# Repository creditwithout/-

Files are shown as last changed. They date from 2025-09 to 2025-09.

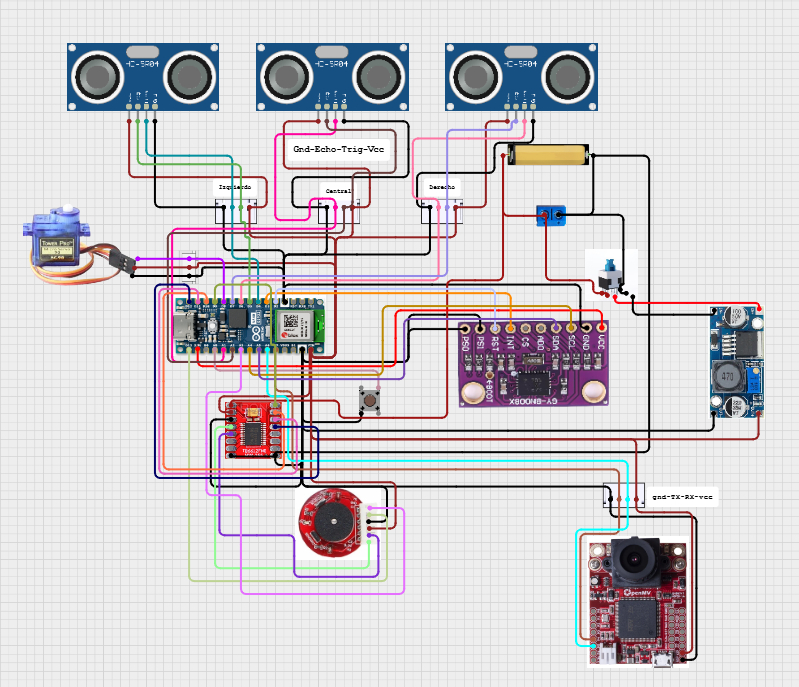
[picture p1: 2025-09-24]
SCHEMES/Cirkit Designer/Captura de pantalla 2025-09-23 232917.png

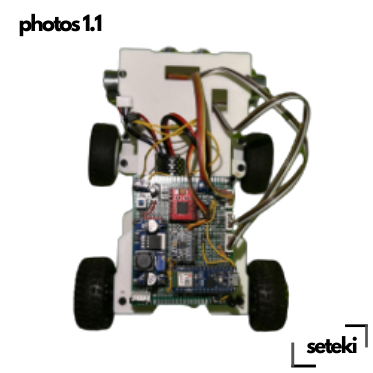
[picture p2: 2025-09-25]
robot photos/1.1/top 1.1.png

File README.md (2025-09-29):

> [!WARNING]
> This repository isn't finished yet, wait until saturday. Any question contact us at setekiteam@gmail.com.
<br>

> [!CAUTION]
> Due to GitHub problems some charts and GIFs can load a little bit slow, so we beg you to be patient while reading to not miss anything, THANKS!

# Seteki® Team🤖
Add a subheading (16 x 5 cm) (4096 x 2160 px)
## Beyond the future! 😎
Animated header







This is the official repository of the Seteki® team that will represent Instituto Episcopal San José in the WRO category: Future Engineers 2025, Panama.
<br><br>

## Overview of our repository folders 📜

```
📦 WRO2025 Seteki
├── 📁 3D-models             # Contains 3D design files for the robot's components
│   ├── 📁 1.1               # 1.1 Models
│   ├── 📁 2.14              # 2.14 Models
│   ├── 📁 3.1 (National)    # 3.1 Models
│   ├── 📁 3D Printer and    # filaments
│   └── 📄 README.md         # 3D models explained
├── 📁 Ara Versions          # Contains an explanation of every ARA Robot
│   ├── 📁 1.1               # ara 1.1
│   ├── 📁 2.14              # 2.14
│   ├── 📁 3.1(National)     # 3.1
│   ├── 📄 ara.md            # A tiny graph of the models
│   └── 📄 README.md         # Explanation of every model
├── 📁 Components            # Every Robot component with and extended information
│   ├── 📁 Arduino Nano ESP32# microcontroller
│   ├── 📁 BNO086            # IMU
│   ├── 📁 HC-SR04           # ultrasonics
│   ├── 📁 INJORA SERVO      # Servomotor
│   ├── 📁 LM2596            # Regulator
│   ├── 📁 MOTOR             # POLOLU
│   ├── 📁 OPEN MV H7 PLUS   # Camera
│   ├── 📁 TB6612FNG         # Motor Driver
│   └── 📄 README.md         # Explanation
├── 📁 SCHEMES               # All of the circuit
│   ├── 📁 Cirkit designer   # Interactive circuit
│   ├── 📁 Fritzing          # Our Circuit in Fritzing
│   ├── 📁 PCB               # Every Of the realization of our PCB
│   └── 📄 README.md         # Explanation
├── 📁 GitHub Printables     # All PDF Githubs ready to print
│   ├── 📁 1.1               # 1.1 pdf
│   ├── 📁 2.14              # 2.14 pdf
│   ├── 📁 3.1(national)     # 3.1 pdf
│   └──📄 README.md          # Explanation
├── 📁 media                 # All our social media
│   └──📄 README.md          # Explanation
├── 📁 Robotlogic & analysis # How our robot is working
│   ├── 📁 Flowcharts        # Flowcharts with explanation
│   ├── 📁 Graphics          # Seteki random photo xd
│   └──📄 README.md          # Explanation
├── 📁 Robot Photos          # Robot videos
│   ├── 📁 1.1               # 1.1 Photos and explanation
│   ├── 📁 2.14              # 2.14 Photos and exlplanation
│   ├── 📁 3.1 (National)    # 3.1 Photos and explanation
│   └──📄 README.md          # 3.1 Photos
├── 📁 src                   # Robot videos
│   ├── 📁 First Challenge   # Codes of the first round
│   ├── 📁 Second Challenge  # Codes of the second round
│   └──📄 README.md          # Explanation
├── 📁 Team Analysis         # Other project studies
│   ├── 📁 Work Schedule     # work time
│   ├── 📁 project cost analy# cost history 3.1
│   ├── 📁 workflow          # a diagram of how we work
│   └──📄 README.md          # Explanation
├── 📁 team photos           # Our photos as participant
│   ├── 📁 Funny photos      # All the funny photos
│   ├── 📁 Photos with tutor # Our photos with our tutor
│   ├── 📁 formal with tutor # Our photos with our tutor
│   ├── 📁 members           # There´s a lot of individual photos
│   └──📄 README.md          # Explanation
├── 📁 video                 # All the robot videos
│   ├── 📁 First Challenge   # All videos of first round
│   ├── 📁 Other videos      # Other explicative videos
│   ├── 📁 Second Challenge  # All videos of the second round
│   └──📄 README.md          # Explanation
└── 📄 README.md             # Main documentation for the project
```

> [!CAUTION]
> Due to GitHub problems some charts and GIFs can load a little bit slow, so we beg you to be patient while reading to not miss anything, THANKS!

## About Us🗣️

<div align="center">
  Trabajo grupal de Los Sentidos Ilustativo Colorido (40 x 25 cm)
</div>

We are Team Seteki, proudly representing Instituto Episcopal San José in Panama’s World Robot Olympiad (WRO) Future Engineers 2025 category. Our mission is to blend technology and innovation, knowing that innovation can go hand-in-hand with responsability.

### Our Philosophy 😎
We are a team in which there are no hierarchies in the team, we each develop our parts and we are all involved and we `KNOW` every part of the realization of this whole project that would be our robor [ARA](https://github.com/creditwithout/-/tree/main/ARA%20Versions), we have values of humility and perseverance as a team, both when we work as a team as well as when we go to compete, we are a team in which two already have experience in what is robotics and specifically the WRO competition and we have a rookie in this world of what robotics is.

With our project we want to innovate and bring something that is well worked to this competition, we want the effort put into this robot to be noticed.

The truth is that our team is in a balance that we feel comfortable and perfect, each one develops a part that is essential for the other part, so we need each other and are values that apart from robotics and technological competition, are values that the WRO is also seeking to establish in all its competitors.

Without further ado, let's continue btw :) 

## Team Name Explication 🥸

The name of our Team ( [Seteki](https://es.wikipedia.org/wiki/Atelopus_zeteki) ), comes from an animal called ‘'[ ***Atelopus zeteki*** ](https://static.inaturalist.org/photos/56362/medium.jpg)’'. 
It is a small species of anuran amphibian of the Bufonidae family.

<div align="center">
  Texto descriptivo
</div>

When we chose this name, it was because we are people who are using the possible resources to develop these robots and technology, but sometimes we forget that all this comes from natural resources and we are taking advantage of all this and we do not take care of it, and as a small annex we wanted to give this message that we also have a responsibility to the world and in addition to this we also want to have our country represented in our team.

> [!WARNING]
> This species is in danger of extinction, more information [here](https://es.wikipedia.org/wiki/Especie_en_peligro_cr%C3%ADtico_de_extinci%C3%B3n).
<br>

## Team presentation 😒

### Jean Sosa
| Name | Description & Rol | GIF | Age | IG | More |
|:---|:---|:---|:---|:---|:---|
| Jean Paul Sosa Cruz  | Robot logic developer, 3D designer and 3D printing, Robot documentation as well as team workflow. for him all is music, and playing instruments, and has a good trayectory in robotics. | Texto descriptivo | 18 |  | [More about him](https://github.com/creditwithout/-/tree/main/team%20photos/members/Jean%20Paul)

### Jonathan Sosa
| Name | Description & Rol | GIF | Age | IG | More |
|:---|:---|:---|:---|:---|:---|
| Jonathan Michael Sosa Cruz  | He is the mechanical genius of the team, he repairs and builds anything and he is in charge of all the robot's circuitry, he only thinks about soccer and getting home to play the bass guitar. | Texto descriptivo | 15 |  | [More about him](https://github.com/creditwithout/-/tree/main/team%20photos/members/Jonathan%20Michael)

### Anthony Gomez
| Name | Description & Rol | GIF | Age | IG | More |
|:---|:---|:---|:---|:---|:---|
| Anthony Bruce Gomez Arjona  | He is the nerdiest of the three, he is the scientist and physicist of the team, he is the developer of the logic and he is in charge of the programming, talk to him about jurasic park and you will have all his attention. | Texto descriptivo | 17 |  | [More about him](https://github.com/creditwithout/-/tree/main/team%20photos/members/Anthony%20Bruce)

### Edgar Ruiz
| Name | Description & Rol | GIF | Age | IG | More |
|:---|:---|:---|:---|:---|:---|
| Edgar Antonio Ruiz Caballero  | Active participant in robotics competitions such as RoboCup Jr , WRO, and others since 2015. - National Winner of RoboCup Jr 2017 and team coachrepresenting Panama in Nagoya, Japan. - Third Place National Winner in WRO 2018 as team coach for The Oxford School. - National Winner of RoboCup Jr 2018 and team coach representing Panama in Sydney, Australia in 2019. - Participant in 2021 STEAM training hosted by Grupo Editorial EDELVIVES in Madrid, Spain. - National Winner of WRO 2022 and team coach representing Panama in Dortmund, Germany. - National Winner of WRO 2024 (World Robot Olympiad) and team coach representing Panama in Izmir, Turkey. | Texto descriptivo | 26 |  | [More about him](https://github.com/creditwithout/-/tree/main/team%20photos/Photos%20with%20tutor)

> [!IMPORTANT]
> You can fin more information of every member by clicking [here](https://github.com/creditwithout/-/tree/main/team%20photos/members).
<br>

## Team Photos😁
- ### [Formal Photo](https://github.com/creditwithout/-/tree/main/team%20photos/formal%20photos)
- ### [Funny Photos](https://github.com/creditwithout/-/tree/main/team%20photos/Funny%20photos)
- ### [Photos with tutor](https://github.com/creditwithout/-/tree/main/team%20photos/Photos%20with%20tutor)

## Robot Name Explication😶‍🌫️

Add a subheading (16 x 5 cm) (4096 x 2160 px) (18)

The name of all versions of our robot (ARA) comes from  [***Ara macao***](https://es.wikipedia.org/wiki/Ara_(animal)#:~:text=Ara%20macao%20(Linnaeus%2C%201758),cyanopterus%20Wiedenfeld%2C%201995%E2%80%93), practically the name of the macaw family. Macaws are large parrots measuring 46 to 51 cm in length and weighing 285 to 287 g in the case of the great macaw, and 90 to 95 cm and 1,708 g in the case of the green-winged macaw.

<div align="center">
  Texto descriptivo
</div>

> [!NOTE]
> More information [here](https://ebird.org/species/scamac1?siteLanguage=es_PA).
<br>

### Robot Versions🚘

| 1.1 | 2.14 | 3.1 (National) |
|:---|:---|:---|
| It's the same configuration than 1.0 version, but de 3D designs had a big improvement.  [more information](https://github.com/creditwithout/-/tree/main/ARA%20Versions/1.1) | this one has 3 ultrasonics and a great improvement in 3D designs. [more information](https://github.com/creditwithout/-/tree/main/ARA%20Versions/2.14) | Has a differential included and more angle for steering [more about](https://github.com/creditwithout/-/tree/main/ARA%20Versions/3.1%20(National)) |

## Mobility Management 

### `3D Models`
- In the [3D Model](https://github.com/creditwithout/-/tree/main/3D%20Models) Folder you will find and extended information about everything relationated with 3D pieces in the robot, an also explaining how we build our differential traction, all about the steering, and also the printer and the filaments we use for the project, anyway here we'll explain all about the differential.

You can also visualize all our 3D Model for the 1.1, 2.14 and the National version By going here

> [!NOTE]
>You can also visualize all our 3D Model for the 1.1, 2.14 and the National version By going [here](https://github.com/creditwithout/-/tree/main/3D%20Models) .
<br>

### ` Differential `

7d3144b8-8908-438d-ba55-42e69fd148e3

`Why we use this mechanism?`
- Because using this mechanism mainly helps us when leaving and parking in the parking lot, since when the robot without differential makes a turn, the wheels will be turning at the same speed, which does not help us since obviously in a turn one wheel will have to travel further than the other, so when the robot has to turn with the differential, it will avoid this skidding that can cause our  old pinion and axle system.

- Some disadvantages are that with the 2.14 robot after the second regional, that well-optimized robot with an 800 RPM motor was doing it in `25 seconds`, but the transmission of speed when there are more gears will cause our robot to go slower, so now we are doing the first round in `42 seconds`.

> [!NOTE]
> [in this folder here](https://github.com/creditwithout/-/tree/main/3D%20Models/3.1%20(National)) You can watch assembly animations of our car.
<br>

<div align="center">
  Texto descriptivo
</div>

## Power Management
Usamos una bateria de [litio 12v](https://github.com/creditwithout/-/tree/main/Components) Con la que la alimentamos al cicuito y al [driver de motor](https://github.com/creditwithout/-/tree/main/Components/TB6612FNG) with which we power our motor. You can find a more detailed explanation of this in the circuits folder, where we explain everything about voltage management and how the voltage components are connected in the robot.

- ### [More information](https://github.com/creditwithout/-/tree/main/SCHEMES/Fritzing/circuit)

## Robot Components
> [!NOTE]
> [in this folder here](https://github.com/creditwithout/-/tree/main/Components) you can find an extended datasheet redacted by the team about every component in the robor.
<br>

 Every robot electrical component
- `Ultrasonic Sensors` [3] [HC-SR04](https://naylampmechatronics.com/blog/10_tutorial-de-arduino-y-sensor-ultrasonico-hc-sr04.html)
  - [Buy Here](https://www.amazon.es/DIGISHUO-ultras%C3%B3nico-medici%C3%B3n-distancia-bricolaje/dp/B0DPZTNKHD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)
  - [More information here](https://github.com/creditwithout/-/tree/main/Components/HC-SRO4)  
- `Motor Driver` [1] [Puente H TB6612FNG 1.2A](https://naylampmechatronics.com/drivers/200-driver-puente-h-tb6612fng.html)  
  - [Buy Here](https://www.amazon.es/CCCAZ1-Controlador-Motor-Microcontrolador-TB6612FNG/dp/B0DM5ZBBH5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)
  - [More information here](https://github.com/creditwithout/-/tree/main/Components/TB6612FNG)
- `Servo motor` [1] [INJORA 11KG](https://www.injora.com/products/injora-injs2065-7kg-high-voltage-waterproof-2065-digital-servo-with-mount-for-1-18-trx4m)
  - [Buy Here](https://www.amazon.com/-/es/digital-impermeable-voltaje-Sub-Micro-Crawler/dp/B0BLBMVYCW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)
  - [More informmation here](https://github.com/creditwithout/-/tree/main/Components/INJORA%20SERVO%2011KG)
- `Motor` [1] [Metal Gearmotor 25Dx65L mm HP 12V with 800 rpm Encoder](https://www.pololu.com/product/4843)
  - [Buy Here](https://www.pololu.com/product/4843)
  - [More information here](https://github.com/creditwithout/-/tree/main/Components/MOTOR)
- `Voltage Regulator` [1] [LM2596](https://naylampmechatronics.com/conversores-dc-dc/196-convertidor-voltaje-dc-dc-step-down-3a-lm2596.html)
  - [Buy Here](https://www.amazon.com/LM2596-Convertidor-alimentaci%C3%B3n-Estabilizador-electr%C3%B3nico/dp/B08RS9BSGB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)
  - [More information here](https://github.com/creditwithout/-/tree/main/Components/LM2596)
- `Interruptor Latching` [1] [Tact Switch](https://es.aliexpress.com/item/32946132279.html?gatewayAdapt=glo2esp)
  - [Buy Here](https://www.amazon.com/-/es/TWTADE-surtido-interruptores-moment%C3%A1neo-valores/dp/B0858XRGYW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)
- `Capacitors` [2] [capacitors](https://quartux.com/blog/que-es-un-capacitor-o-condensador-electrico/)
  - [Buy Here](https://www.amazon.com/ALLECIN-surtido-condensadores-electrol%C3%ADticos-aluminio/dp/B0C1VBXCQM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)
- `Male female conectors` [12] [XH-4Y](https://www.walmart.com/ip/2-54mm-Pitch-Connector-Kits-4-Pin-Male-Female-Header-Socket-4Pin-Housing-Cable-Adapter-and-Crimp-DIP-Kit-600pcs/1723812568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)
  - [Buy Here](https://www.amazon.com/-/es/JST-conectores-terminales-compatible-XH2-2-126/dp/B0DN6LGG94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)
- `Gyroscope BNO086` [1] [BNO086 (IMU Sensor)](https://naylampmechatronics.com/blog/45_tutorial-mpu6050-acelerometro-y-giroscopio.html)
  - [Buy Here](https://www.amazon.com/-/es/unidades-GY-521-aceler%C3%B3metro-giroscopio-convertidor/dp/B07RXQGGJX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)
  - [More information](https://github.com/creditwithout/-/tree/main/Components/BNO086)
- `Micro-controller` [1] [Arduino NANO ESP32](https://store.arduino.cc/products/nano-esp32?srsltid=AfmBOor1ZPTTOx_mqwjYCxh9cpnrrSOmZiry-TUbDsQwkmkYgxsAu0NA)
  - [Buy Here](https://www.amazon.com/-/es/Arduino-Nano-ESP32-encabezados-ABX00083/dp/B0C947BHK5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)
  - [More information](https://github.com/creditwithout/-/tree/main/Components/Arduino%20Nano%20ESP32)
- `Terminal` [1] [PCB Terminal](https://www.ebay.com/itm/176852835599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)
  - [Buy Here](https://www.amazon.com/Conector-terminales-proyectos-electr%C3%B3nica-dom%C3%A9stica/dp/B09ZXK9WHW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)
- `Prototype wires` [32] [Prototype wires](https://shop.complubot.com/10-cables-prototipado-m--m-100-mm-p-1-50-142/)
  - [Buy Here](https://www.amazon.com/b%C3%B3vedas-0-079-4-921-Flexible-Breadboard-Connecting/dp/B08YRGVYPV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)
- `Normal Wires` [11] [Normal Wires](https://electric-house.com/en/new-cables-wires-accessories/british-standard-wires-nya/normal-nya-wires.html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)
  - [Buy Here](https://www.amazon.com/Aypzuke-compatible-proyectos-Arduino-Raspberry/dp/B0BTT31CBC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)
- `Camera` [1] [Open MV H7 Plus](https://openmv.io/products/openmv-cam-h7-plus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)
  - [Buy Here](https://www.amazon.com/-/es/OpenMV-Cam-Plus-Procesamiento-Aprendizaje/dp/B09WYQMDX2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)
  - [More information](https://github.com/creditwithout/-/tree/main/Components/Open%20MV%20H7%20Plus)
- `Lipo Battery` [1] [Airsoft LIPPO Battery 11.1V](https://ampedairsoft.com/high-power-airsoft-hpa-lipo-battery-deans/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)
  - [Buy Here](https://ampedairsoft.com/high-power-airsoft-hpa-lipo-battery-tamiya/)
- `Ceramic Capacitors` [2] [Ceramic Capacitors](https://ampedairsoft.com/high-power-airsoft-hpa-lipo-battery-deans/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)
  - [Buy Here](https://ampedairsoft.com/high-power-airsoft-hpa-lipo-battery-tamiya/)

> [!WARNING]
> You can see a more extenden explanation of every component in the folders, anyway in the component list you can find the link to go to a extended explanation of every component, thanks
<br>

## Schemes

For the national we aim to improve all of our circuit, we decide to give to the judges more interactive circuit an better explanation un the folders just to have a better understanding on everything around the project.

- ### [Cirkit designer](https://github.com/creditwithout/-/tree/main/SCHEMES/Cirkit%20Designer)
- ### [Cirkit designer cirkit public viewer](https://app.cirkitdesigner.com/project/14ea10bb-b8b8-4b1f-92cd-de119d128b88)
- ### [Fritzing](https://github.com/creditwithout/-/tree/main/SCHEMES/Fritzing)
- ### [PCB](https://github.com/creditwithout/-/tree/main/SCHEMES/PCB)

### `PCB 3D VIEWER`

Trabajo grupal de Los Sentidos Ilustativo Colorido (Mobile Video) (6)

## Robot logic and analysis

For us, it is very important that when explaining our robot, we can use diagrams and graphs that show the actual flow of logic, programming, and all the decisions that enable our ARA Robot to execute its respective rounds. We have flowcharts that show the decisions to be followed for each round, as well as specialized diagrams of the internal decisions made by some components within the code. We also have graphs that explain the actual operation mathematically and physically, with very short standard deviations in the execution of everything.

- ### [Flowcharts](https://github.com/creditwithout/-/tree/main/robot%20logic%20and%20analysis/flowcharts)
   - #### [First Challenge](https://github.com/creditwithout/-/tree/main/robot%20logic%20and%20analysis/flowcharts/First%20challenge)
   - #### [Second Challenge](https://github.com/creditwithout/-/tree/main/robot%20logic%20and%20analysis/flowcharts/Second%20Challenge)
     
- ### [Graphics](https://github.com/creditwithout/-/tree/main/robot%20logic%20and%20analysis/graphics)

## SRC
Here you will find the two complete source codes for each round, in order to remain faithful to the engineering process, as well as detailed explanations of the most interesting and complex parts of our codes.

- ### [First Challenge](https://github.com/creditwithout/-/tree/main/src/First%20Challenge)

- ### [Second Challenge](https://github.com/creditwithout/-/tree/main/src/Second%20Challenge)
    - ### [Camera](https://github.com/creditwithout/-/tree/main/src/Second%20Challenge/camera)

## [Team Analysis](https://github.com/creditwithout/-/tree/main/team%20analysis)

- ### [Work team Schedule](https://github.com/creditwithout/-/tree/main/team%20analysis/Work%20Schedule)
- ### [Project cost Schedule](https://github.com/creditwithout/-/tree/main/team%20analysis/project%20cost%20analysis)
- ### [WorkFlow](https://github.com/creditwithout/-/tree/main/team%20analysis/workflow)

## Performative Videos

### `You'll find every video in` [here](https://github.com/creditwithout/-/tree/main/video)

## Media

### 'And all our social media, clash royal clan and web page in' [here](https://github.com/creditwithout/-/tree/main/media%20)

---

## References
https://fritzing.org/download/
https://openmv.io/pages/download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
https://www.ni.com/es/shop/labview/pid-theory-explained.html#:~:text=Un%20controlador%20PID%20es%20un,%2C%20velocidad%2C%20presi%C3%B3n%20y%20voltaje.
https://www.arduino.cc/
https://es.wikipedia.org/wiki/Arduino
https://wro-association.org/
https://es.wikipedia.org/wiki/Microcontrolador#:~:text=Un%20microcontrolador%20(abreviado%20%C2%B5C%2C%20UC,que%20cumplen%20una%20tarea%20espec%C3%ADfica.
https://es.wikipedia.org/wiki/Impresi%C3%B3n_3D
https://scoring.wro-association.org/es/
https://docs.github.com/es/get-started/writing-on-github/getting-started-with-writing-and-formatting-on-github/basic-writing-and-formatting-syntax
https://es.wikipedia.org/wiki/Sensor_ultras%C3%B3nico
https://naylampmechatronics.com/

> [!CAUTION]
> Due to GitHub problems some charts and GIFs can load a little bit slow, so we beg you to be patient while reading to not miss anything, THANKS!

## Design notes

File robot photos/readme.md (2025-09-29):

# Robot Photos
Add a subheading (16 x 5 cm) (4096 x 2160 px) (2)
Here you will find not only photos of the ARA 3.1 national version, but also photos of the robot that competed in the two previous regional competitions, thus maintaining the competition's philosophy of creating an engineering process and documenting everything along the way.

# End Page 
Seteki 2025 - Robot photos

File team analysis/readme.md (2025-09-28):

# Team Analysis
Add a subheading (16 x 5 cm) (4096 x 2160 px) (17)

Here you'll find the work schedule and the workflow of the journey in this project and also a cost analysis just for the ARA ROBOT 3.1

# End Page
Seteki 2025 - Team analysis

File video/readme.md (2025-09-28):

# ARA 3.1 Challenges videos

Add a subheading (16 x 5 cm) (4096 x 2160 px) (16)

## [Here](https://www.youtube.com/@setekiteam) you can visit our youtube video, and every folder will have the link to the exact video, and briefly mp4 short.

# End Page
Seteki 2025 - Videos

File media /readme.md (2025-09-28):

# All Our Social Media

Copy of Add a subheading (16 x 5 cm) (4096 x 2160 px) (12)

We count with several ways to share our project with the world!

 - [Youtube](https://www.youtube.com/@setekiteam)

Here you'll find not just the videos of the robot making the rounds, you'll also find other type of videos where we are explaining the project.

 - [Instagram](https://www.instagram.com/setekiteam/)

Here you'll find our day to day, because this is a engineering process.

 - [Clash royal seteki clan](https://link.clashroyale.com/invite/clan/es?tag=G8YULLJP&token=3jhdxkac&platform=iOS)

Being in robotics is also a lot of getting mentally tire, so sometimes is okey to distract your mind with hobbies like music, sports, games and then get fresh to get back to work, that's why we have a seteki clash royal CLAN. jijijija!

 - [Seteki web page](https://seteki.vercel.app/)

Copy of Add a subheading (16 x 5 cm) (4096 x 2160 px) (14)

# End Page
Seteki 2025 - MEDIA

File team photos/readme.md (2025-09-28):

# Team Photos🦾
Add a subheading (16 x 5 cm) (4096 x 2160 px) (3)

# End Page
Seteki 2025

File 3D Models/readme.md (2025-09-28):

# Every 3D models
Copy of Add a subheading (16 x 5 cm) (4096 x 2160 px)

In this set of folders, you will find all the models that can be viewed and downloaded in ``` (.stl) ``` files for all the models of our ARA robot. Each folder will also have an explanation of all the 3D models corresponding to each version. To review the current version of the national competition in Panama 2025, check folder ```3.1```, where you will find everything related to the robot that will compete in the national competition.



--------------------------
### Seteki -- 3D Models

# End Page 
Seteki 2025 - 3D models

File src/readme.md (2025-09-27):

# SRC Folder

Add a subheading (16 x 5 cm) (4096 x 2160 px) (8)

In this folder, you will find all the codes and most important parts explained and documented in English. The readme file explains the fundamental parts, and the complete code will be uploaded to the same folder in its respective native file format, with each code commented on in English and accompanied by a detailed explanation.

## Here you'll find:

- ### [First Challenge](https://github.com/creditwithout/-/tree/main/src/First%20Challenge) 
- ### [Second Challenge](https://github.com/creditwithout/-/tree/main/src/Second%20Challenge)
   - [Camera Code](https://github.com/creditwithout/-/tree/main/src/Second%20Challenge/camera)

# End Page
Seteki 2025 - SRC

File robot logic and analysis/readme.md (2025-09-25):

# Robot logic and analysis.
Add a subheading (16 x 5 cm) (4096 x 2160 px) (1)

Here we can find physical and mathematical explanations of everything that happens in the robot's programming and logic. We will also find flowcharts of the autonomous decisions made by each component, and graphs that show specific problems graphically so that they can be better understood.

# End Page
Seteki 2025 - Robot logic and analysis

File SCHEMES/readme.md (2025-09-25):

# Schemes

Copy of Add a subheading (16 x 5 cm) (4096 x 2160 px) (6)

This folder contains in-depth information about our robot's circuit, including our PCB, explanations, and various diagrams, especially about the circuit. Everything is covered in depth here, because the main readme file is much more summarized than the folders.

Trabajo grupal de Los Sentidos Ilustativo Colorido (Mobile Video) (6)

# End page
Seteki 2025 - Schemes

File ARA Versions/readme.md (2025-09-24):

# Every ARA Robot that has faced a competition 😁

Copy of Add a subheading (16 x 5 cm) (4096 x 2160 px) (1)

### Robot Versions🚘

| 1.0 | 1.1 | 2.12 | 2.13 | 2.14 | 3.1
|:---|:---|:---|:---|:---|:---|
| It has 3 ultrasonics, No differential | It's the same configuration than 1.1 version, but de 3D designs had a big improvement. | Has only camera, no ultrasonics, has a differential integrated. | This one has 2 ultrasonics and the camera, we quit differential to keed developing it | this one has 3 ultrasonics and a great improvement in 3D designs. | THIS ONE INTEGRATE A DIFFERENTIAL IN THE TRACTION AND HAS 3 ULTRASONICS, AND NOW COUNTS WITH A DESIGNED PCB AND MANUFACTERED IN HONG KONG, FOR MAKE OUR CIRCUIT A LOT BETTER. |

## NATIONAL

For the national our robot is the ARA 3.0

Trabajo grupal de Los Sentidos Ilustativo Colorido (7)

# end page - seteki
Seteki 2025 - GitHub 3.1 - creditwhitout [Home main page](https://github.com/creditwithout/-/blob/main/README.md)

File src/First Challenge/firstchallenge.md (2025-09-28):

```ino
#include "SparkFun_BNO080_Arduino_Library.h"
#include <Wire.h>
#include <ESP32Servo.h>
#include <stdlib.h>
#include <math.h>
#include <string.h>

#if __has_include(<NewPing.h>)
#include <NewPing.h>
#define USE_NEWPING 1
#else
#define USE_NEWPING 0
#endif

// ==================== CONFIGURABLE PARAMETERS ====================
// IMU and I2C bus configuration
const uint8_t I2C_SDA_PIN = A4;  // Current user wiring configuration
const uint8_t I2C_SCL_PIN = A5;    // I2C clock line pin
const uint8_t BNO08X_INT_PIN = 2;  // BNO080 interrupt pin for data ready signal
const uint8_t BNO08X_RST_PIN = 3;  // BNO080 reset pin for hardware reset capability
const uint8_t BNO08X_ADDR = 0x4B;  // I2C address of BNO080 sensor

// Motor driver and auxiliary hardware pins
const int pwma = 9;           // PWM control pin for motor speed
const int ain2 = 10;          // Motor direction control pin (L298N)
const int ain1 = 11;          // Motor direction control pin (L298N)
const int stby = 12;          // Standby pin to enable/disable motor driver
const int startButtonPin = A0; // Start button input pin

// Servo motor configuration
const int servoPin = 8;        // Servo control pin
const int servoNeutral = 90;    // Neutral position (straight ahead)
const int servoMinAngle = 10;   // Minimum servo angle limit
const int servoMaxAngle = 170;  // Maximum servo angle limit

// Ultrasonic sensor configuration
#define TRIG_IZQUIERDO 5    // Left ultrasonic trigger pin
#define ECHO_IZQUIERDO 4     // Left ultrasonic echo pin
#define TRIG_CENTRO A2       // Center ultrasonic trigger pin
#define ECHO_CENTRO A1       // Center ultrasonic echo pin
#define TRIG_DERECHA 6       // Right ultrasonic trigger pin
#define ECHO_DERECHA 7       // Right ultrasonic echo pin
const unsigned int MAX_US_DISTANCE_CM = 200;     // Maximum measurable distance
const long TIMEOUT_ULTRASONICO = 20000;          // Timeout for ultrasonic readings
const float DISTANCIA_MAX_VALIDA = 500.0;        // Maximum valid distance reading
const float DISTANCIA_MIN_VALIDA = 1.0;          // Minimum valid distance reading
const float umbralRatioLateral = 0.6;            // Lateral threshold ratio for opening detection
const float umbralRatioCentral = 1.3;            // Central threshold ratio for wall detection
const unsigned long MIN_INTERVALO_PING_MS = 15; // Minimum interval between ultrasonic pings

// PID controller parameters for yaw control
float Kp = 1.5, Ki = 0.01, Kd = 0.2;        // Normal navigation PID gains
float Kp_turn = 0.5, Ki_turn = 0.25, Kd_turn = 1.00;  // Turning maneuver PID gains
float Kp_stab = 1.02, Ki_stab = 0.03, Kd_stab = 1.00; // Stabilization PID gains
const unsigned long sampleInterval = 20;       // PID sample time in microseconds
const float integralLimit = 40.0;              // Integral windup protection limit
const float deadband = 0.5;                    // Deadband for yaw error to prevent oscillation

// Maneuver timing and control parameters
const unsigned long TIMEOUT_MANIOBRA = 4000;           // Maximum time for turn maneuver
const float TURN_ANGLE_TOLERANCE = 2;                   // Angle tolerance for turn completion
const unsigned long tiempoEstabilizacion = 300;        // Stabilization phase duration
const unsigned long tiempoCorreccion = 400;            // Correction phase duration
const unsigned long TIMEOUT_CORRECCION = 800;          // Maximum correction phase timeout
const float CORRECTION_ANGLE_TOLERANCE = 5;             // Yaw stability tolerance for correction
const int NUM_CURVAS_ANTES_DE_PARAR = 12;              // Number of turns before parking sequence

// Motor speed settings for different phases
const int velocidadNormal = 255;        // Normal navigation speed
const int velocidadGiro = 255;          // Turning maneuver speed
const int velocidadEstabilizacion = 255; // Stabilization phase speed
const int velocidadCorreccion = 255;     // Correction phase speed
const int velocidadCorreccionMin = 180;  // Minimum correction speed for ramping
const int velocidadCorreccionMax = 255;  // Maximum correction speed for ramping

// Parking algorithm parameters
float Kp_parking_lateral = 3.0;                              // Lateral positioning PID proportional gain
float Kd_parking_lateral = 0.4;                              // Lateral positioning PID derivative gain
const float DEADBAND_PARKING_LATERAL = 5.0;                  // Deadband for lateral positioning
const float DISTANCIA_CENTRAL_OBJETIVO_TOLERANCIA_PARKING = 5.0; // Front distance tolerance for parking
const int VELOCIDAD_PARKING_AVANCE = 105;                    // Forward speed during parking
const int VELOCIDAD_PARKING_RETROCESO = 105;                 // Reverse speed during parking
const int VELOCIDAD_PARKING_ALINEACION_LATERAL = 105;        // Lateral alignment speed
const unsigned long TIMEOUT_PARKING_SUBFASE = 10000;        // Timeout for parking subphases
const unsigned long intervalo = 1000;                        // Interval for alternating parking attempts

// Signal filtering parameters
#define FILTER_SIZE 1  // Size of median filter window for ultrasonic readings
// ================= END OF CONFIGURABLE PARAMETERS =================

#if USE_NEWPING
// Limiting maximum distance reduces echo wait time and speeds up each measurement
NewPing sonarIzq(TRIG_IZQUIERDO, ECHO_IZQUIERDO, MAX_US_DISTANCE_CM);
NewPing sonarCen(TRIG_CENTRO,    ECHO_CENTRO,    MAX_US_DISTANCE_CM);
NewPing sonarDer(TRIG_DERECHA,   ECHO_DERECHA,   MAX_US_DISTANCE_CM);
// --- Asynchronous scheduler for NewPing (one ping at a time, non-blocking) ---
enum SensorId { SEN_CEN = 0, SEN_IZQ = 1, SEN_DER = 2 };  // Sensor identification enum
volatile unsigned int echoUs[3] = {0, 0, 0};            // Echo timing results in microseconds
volatile bool echoListo[3] = {false, false, false};     // Echo completion flags
volatile bool pingEnCurso = false;                      // Current ping operation flag
static SensorId sensorEnCurso = SEN_CEN;                // Currently active sensor

void echoCheckCen() {
  if (sonarCen.check_timer()) {
    echoUs[SEN_CEN] = sonarCen.ping_result;  // Store center sensor echo timing
    echoListo[SEN_CEN] = true;               // Mark center echo as ready
    pingEnCurso = false;                     // Free up ping scheduler
  }
}
void echoCheckIzq() {
  if (sonarIzq.check_timer()) {
    echoUs[SEN_IZQ] = sonarIzq.ping_result;  // Store left sensor echo timing
    echoListo[SEN_IZQ] = true;               // Mark left echo as ready
    pingEnCurso = false;                     // Free up ping scheduler
  }
}
void echoCheckDer() {
  if (sonarDer.check_timer()) {
    echoUs[SEN_DER] = sonarDer.ping_result;  // Store right sensor echo timing
    echoListo[SEN_DER] = true;               // Mark right echo as ready
    pingEnCurso = false;                     // Free up ping scheduler
  }
}

void iniciarPing(SensorId s) {
  if (pingEnCurso) return;  // Prevent overlapping ping operations
  switch (s) {
    case SEN_CEN: sonarCen.ping_timer(echoCheckCen); break;  // Start center sensor ping
    case SEN_IZQ: sonarIzq.ping_timer(echoCheckIzq); break;  // Start left sensor ping
    case SEN_DER: sonarDer.ping_timer(echoCheckDer); break;  // Start right sensor ping
  }
  sensorEnCurso = s;     // Track which sensor is currently active
  pingEnCurso = true;    // Mark ping operation as in progress
}

void servicioUltrasonidos() {
  // Fair scheduling pattern: CEN -> IZQ -> CEN -> DER -> ...
  static uint8_t fase = 0; // 0=CEN,1=IZQ,2=CEN,3=DER
  unsigned long ahoraMs = millis();
  if (pingEnCurso) return;  // Skip if ping already in progress

  // Check minimum interval constraints for each sensor
  bool puedeCen = (ahoraMs - ultimoPingCenMs) >= MIN_INTERVALO_PING_MS;
  bool puedeIzq = (ahoraMs - ultimoPingIzqMs) >= MIN_INTERVALO_PING_MS;
  bool puedeDer = (ahoraMs - ultimoPingDerMs) >= MIN_INTERVALO_PING_MS;

  // Try to find next available sensor in fair rotation pattern
  for (uint8_t intentos = 0; intentos < 4; intentos++) {
    uint8_t f = (fase + intentos) % 4;
    if ((f == 0 || f == 2) && puedeCen) {  // Center sensor slots (0 and 2)
      iniciarPing(SEN_CEN);
      ultimoPingCenMs = ahoraMs;
      fase = (f + 1) % 4;
      return;
    }
    if (f == 1 && puedeIzq) {  // Left sensor slot (1)
      iniciarPing(SEN_IZQ);
      ultimoPingIzqMs = ahoraMs;
      fase = (f + 1) % 4;
      return;
    }
    if (f == 3 && puedeDer) {  // Right sensor slot (3)
      iniciarPing(SEN_DER);
      ultimoPingDerMs = ahoraMs;
      fase = (f + 1) % 4;
      return;
    }
  }
}
#endif

BNO080 myIMU;        // IMU sensor object for orientation data
Servo steeringServo;  // Servo object for steering control

float yawOffset = 0.0f;  // Yaw offset for relative orientation
bool offsetSet = false;   // Flag indicating if yaw offset has been calibrated

float setpoint = 0.0, targetSetpoint = 0.0;  // Current and target yaw setpoints
float error = 0.0, prevError = 0.0;           // Current and previous yaw errors
float integral = 0.0, derivative = 0.0, pidOutput = 0.0;  // PID controller terms
unsigned long prevTimePID = 0;                // Previous PID calculation timestamp
float setpoint_actual_debug = 0.0;           // Debug variable for setpoint tracking
float currentYaw = 0.0f;                     // Current relative yaw angle
float dt_global = 0.02f;                     // Global delta time for PID calculations

// --- Motor speed ramping variables ---
int velocidadActualMotor = 0;      // Current motor speed
int velocidadObjetivoMotor = 0;    // Target motor speed
enum DireccionMotor { MOTOR_DETENIDO, MOTOR_ADELANTE, MOTOR_ATRAS };  // Motor direction states
DireccionMotor direccionMotor = MOTOR_DETENIDO;  // Current motor direction

enum EstadoRobot { NORMAL, EN_MANIOBRA, ESTABILIZANDO, CORRIGIENDO, PARKING, DETENIDO };  // Robot state machine
EstadoRobot estadoActual = NORMAL;  // Current robot state
const char* estadoNombres[] = {"NORMAL", "EN_MANIOBRA", "ESTABILIZANDO", "CORRIGIENDO", "PARKING", "DETENIDO"};  // State names for debugging

unsigned int contadorCurvas = 0;                    // Counter for completed turns
enum DireccionGiro { NINGUNA, IZQUIERDA, DERECHA };  // Turn direction enumeration
DireccionGiro direccionPrimerGiro = NINGUNA;         // Direction of first turn (for consistency)
unsigned long tiempoInicioManiobra = 0;              // Turn maneuver start timestamp
unsigned long estabilizacionInicio = 0;              // Stabilization phase start timestamp
unsigned long correccionInicio = 0;                  // Correction phase start timestamp
float distanciaCentralInicial = 0.0;                 // Initial center distance reference

float lecturasIzquierdo[FILTER_SIZE], lecturasCentro[FILTER_SIZE], lecturasDerecho[FILTER_SIZE];  // Ultrasonic reading buffers
int indiceLecturaIzquierdo = 0, indiceLecturaCentro = 0, indiceLecturaDerecho = 0;  // Buffer indices
float distanciaIzquierdoFiltrada = 0.0, distanciaCentroFiltrada = 0.0, distanciaDerechoFiltrada = 0.0;  // Filtered distances
float distanciaUltrasonicoCentro_dbg = 999.9;  // Debug variable for center distance

enum SubEstadoParking { SUB_PARKING_NO_INICIADO, SUB_PARKING_ALINEACION_LATERAL, SUB_PARKING_ALINEACION_FRONTAL, SUB_PARKING_FINALIZADO };  // Parking sub-states
SubEstadoParking subEstadoParkingActual = SUB_PARKING_NO_INICIADO;  // Current parking sub-state
bool paredObjetivoParkingEsIzquierda = false;  // Which side wall to align with
float errorParkLat = 0.0, prevErrorParkLat = 0.0, pdOutputParkLat = 0.0;  // Lateral parking PID terms
unsigned long tiempoInicioSubEstadoParking = 0, tiempoInicioIntentoActual = 0;  // Parking timing variables
float distanciaIzquierdoInicial = 50.0, distanciaDerechoInicial = 50.0;  // Initial lateral distances
bool intentandoAlineacionLateralActual = true;  // Flag for alternating lateral alignment attempts

volatile bool imuDataReady = false;  // IMU data ready flag
unsigned long ultimoTiempoDatosImu = 0;  // Last IMU data timestamp
// Last ping time per sensor (to avoid readings too close together)
unsigned long ultimoPingIzqMs = 0;  // Last left sensor ping time
unsigned long ultimoPingCenMs = 0;  // Last center sensor ping time
unsigned long ultimoPingDerMs = 0;  // Last right sensor ping time

// --- Robot Functions ---

void setReports(void) {
  Serial.println("Enabling Rotation Vector...");
  myIMU.enableRotationVector(50);  // Enable rotation vector reports at 50Hz
  Serial.println(F("Rotation Vector enabled."));
}

bool iniciarIMURobusto() {
  const uint8_t posiblesDirecciones[2] = {0x4B, 0x4A};  // Possible I2C addresses for BNO080
  // Add slower speeds to attempt communication stabilization without pull-ups
  const uint32_t clocks[4] = {100000, 50000, 20000, 400000};  // I2C clock speeds to try 
  Serial.print("INT level before init: "); Serial.println(digitalRead(BNO08X_INT_PIN));
  for (uint8_t ci = 0; ci < 4; ci++) { // Updated loop limit to 4
    Wire.setClock(clocks[ci]);
    for (uint8_t ai = 0; ai < 2; ai++) {
      uint8_t addr = posiblesDirecciones[ai];
      Serial.print("Trying IMU at 0x"); Serial.print(addr, HEX);
      Serial.print(" @I2C"); Serial.print(clocks[ci]/1000); Serial.print("k without INT/RST...");
      if (myIMU.begin(addr, Wire)) {
        Serial.println("OK");
        return true;
      }
      Serial.println("fail");
      Serial.print("INT level after attempt without INT: "); Serial.println(digitalRead(BNO08X_INT_PIN));
    }
  }
  Serial.println("Scanning I2C bus...");
  for (uint8_t address = 1; address < 127; address++) {
    Wire.beginTransmission(address);
    uint8_t error = Wire.endTransmission();
    if (error == 0) {
      Serial.print("I2C device found at 0x");
      Serial.println(address, HEX);
    }
  }
  return false;
}

// (Removed: custom gyroscope reset/calibration logic)

// (Removed: sample-based calibration routine; offset is set on first reading)

float medirDistancia(int trigPin, int echoPin) {
#if USE_NEWPING
    unsigned int cm = 0;
    if (trigPin == TRIG_IZQUIERDO && echoPin == ECHO_IZQUIERDO) {
        cm = sonarIzq.ping_cm();  // Get left sensor distance
    } else if (trigPin == TRIG_CENTRO && echoPin == ECHO_CENTRO) {
        cm = sonarCen.ping_cm();  // Get center sensor distance
    } else if (trigPin == TRIG_DERECHA && echoPin == ECHO_DERECHA) {
        cm = sonarDer.ping_cm();  // Get right sensor distance
    } else {
        cm = 0;  // Invalid pin combination
    }
    if (cm == 0) return 999.9;  // Return invalid distance if no echo
    float dist = (float)cm;
    if (dist < DISTANCIA_MIN_VALIDA || dist > DISTANCIA_MAX_VALIDA) return 999.9;  // Validate distance range
    return dist;
#else
    digitalWrite(trigPin, LOW); delayMicroseconds(2);     // Clear trigger pin
    digitalWrite(trigPin, HIGH); delayMicroseconds(10);   // Send 10us trigger pulse
    digitalWrite(trigPin, LOW);                           // Clear trigger pin
    long duration = pulseIn(echoPin, HIGH, TIMEOUT_ULTRASONICO);  // Measure echo duration
    if (duration == 0) return 999.9;  // Return invalid if timeout
    float dist = (duration * 0.0343) / 2.0;  // Convert to distance (cm)
    if (dist < DISTANCIA_MIN_VALIDA || dist > DISTANCIA_MAX_VALIDA) return 999.9;  // Validate range
    return dist;
#endif
}

int compareFloat(const void* a, const void* b) {
    float fa = *(const float*) a; float fb = *(const float*) b;  // Cast void pointers to float
    return (fa > fb) - (fa < fb);  // Return comparison result for sorting
}

float calcularMediana(float arr[], int n) {
    if (n <= 0) return 999.9;  // Invalid array size
    if (n == 1) return arr[0];  // Single element case
    float tempArr[n]; memcpy(tempArr, arr, n * sizeof(float));  // Create working copy
    qsort(tempArr, n, sizeof(float), compareFloat);  // Sort array
    int invalidos = 0; for(int i=0; i<n; i++) { if(tempArr[i] >= 999.0) invalidos++; }  // Count invalid readings
    if(invalidos > n / 2) return 999.9;  // Too many invalid readings
    int primerValidoIdx = 0;
    while(primerValidoIdx < n && tempArr[primerValidoIdx] >= 999.0) { primerValidoIdx++; }  // Find first valid reading
    int medianaIdx = primerValidoIdx + (n - invalidos - 1) / 2;  // Calculate median index of valid readings
    if(medianaIdx < 0) medianaIdx = 0;  // Bounds checking
     if (medianaIdx >= n) medianaIdx = n - 1;  // Bounds checking
    return tempArr[medianaIdx];  // Return median value
}

void moverAdelante(int velocidad) {
    direccionMotor = MOTOR_ADELANTE;  // Set motor direction to forward
    velocidadObjetivoMotor = constrain(velocidad, 0, 255);  // Constrain speed to valid range
}

void detenerMotor() {
    direccionMotor = MOTOR_DETENIDO;  // Set motor direction to stopped
    velocidadObjetivoMotor = 0;       // Set target speed to zero
}

float calcularErrorAngular(float target, float current) {
    float diff = target - current;  // Calculate raw difference
    while (diff <= -180.0) diff += 360.0;  // Normalize to [-180, 180] range
    while (diff > 180.0) diff -= 360.0;    // Normalize to [-180, 180] range
    return diff;  // Return normalized angular error
}

void moverAtras(int velocidad) {
    direccionMotor = MOTOR_ATRAS;  // Set motor direction to reverse
    velocidadObjetivoMotor = constrain(velocidad, 0, 255);  // Constrain speed to valid range
}

void setup() {
    Serial.begin(115200);  // Initialize serial communication
    unsigned long inicioEsperaSerial = millis();  // Start serial wait timer
    while (!Serial && millis() - inicioEsperaSerial < 2000) {  // Wait for serial connection or timeout
        delay(10);
    }
    pinMode(BNO08X_INT_PIN, INPUT_PULLUP);  // Configure INT pin with pullup
    pinMode(BNO08X_RST_PIN, OUTPUT);        // Configure reset pin as output
    digitalWrite(BNO08X_RST_PIN, HIGH);     // Keep reset pin high (not reset)
    Wire.begin(I2C_SDA_PIN, I2C_SCL_PIN);   // Initialize I2C with custom pins
    Wire.setClock(400000);                  // Set I2C clock to 400kHz
    Serial.println("1rondaV2.0");          // Print version info

    steeringServo.attach(servoPin);    // Attach servo to control pin
    steeringServo.write(servoNeutral);  // Set servo to neutral position

    if (!iniciarIMURobusto()) {
        Serial.println(F("CRITICAL FAILURE: BNO080 not detected. Check connections."));
        while (1);  // Halt execution if IMU not found
    }
    Serial.println(F("BNO080 found."));
    delay(100);     // Allow IMU to stabilize
    setReports();   // Configure IMU reports
    
    ultimoTiempoDatosImu = millis(); // Initialize watchdog timer

    pinMode(TRIG_IZQUIERDO, OUTPUT); pinMode(ECHO_IZQUIERDO, INPUT);  // Configure left ultrasonic pins
    pinMode(TRIG_CENTRO, OUTPUT); pinMode(ECHO_CENTRO, INPUT);       // Configure center ultrasonic pins
    pinMode(TRIG_DERECHA, OUTPUT); pinMode(ECHO_DERECHA, INPUT);     // Configure right ultrasonic pins

    Serial.println("Filling initial filter buffers...");
    for (int i = 0; i < FILTER_SIZE; i++) {
        lecturasIzquierdo[i] = medirDistancia(TRIG_IZQUIERDO, ECHO_IZQUIERDO); delay(15);  // Fill left buffer
        lecturasCentro[i] = medirDistancia(TRIG_CENTRO, ECHO_CENTRO); delay(5);             // Fill center buffer
        lecturasDerecho[i] = medirDistancia(TRIG_DERECHA, ECHO_DERECHA); delay(15);        // Fill right buffer
    }
    distanciaIzquierdoFiltrada = calcularMediana(lecturasIzquierdo, FILTER_SIZE);  // Initialize filtered distances
    distanciaCentroFiltrada = calcularMediana(lecturasCentro, FILTER_SIZE);
    distanciaDerechoFiltrada = calcularMediana(lecturasDerecho, FILTER_SIZE);
    
    Serial.println("-> Using ultrasonic for initial central distance.");
    distanciaCentralInicial = (distanciaCentroFiltrada < 999.0) ? distanciaCentroFiltrada : 100.0;  // Set reference distance
    
    distanciaIzquierdoInicial = (distanciaIzquierdoFiltrada < 999.0) ? distanciaIzquierdoFiltrada : 25.0;  // Set left reference
    distanciaDerechoInicial = (distanciaDerechoFiltrada < 999.0) ? distanciaDerechoFiltrada : 25.0;   // Set right reference

    Serial.print("Initial central distance (effective): "); Serial.println(distanciaCentralInicial);
    
    pinMode(pwma, OUTPUT); pinMode(ain2, OUTPUT); pinMode(ain1, OUTPUT); pinMode(stby, OUTPUT);  // Configure motor pins
    digitalWrite(stby, HIGH);  // Enable motor driver
    detenerMotor();            // Initialize motor as stopped

    currentYaw = 0.0f;        // Initialize yaw angle
    setpoint = 0.0f;          // Initialize setpoint
    targetSetpoint = 0.0;     // Initialize target setpoint
    prevTimePID = micros();   // Initialize PID timing
    estadoActual = NORMAL;    // Set initial robot state

    pinMode(startButtonPin, INPUT_PULLUP);  // Configure start button pin
    Serial.println("IMU ready. Press button to start...");
    while (digitalRead(startButtonPin) == HIGH) {  // Wait for button press
        delay(50);
    }
    Serial.println("Button pressed. Starting movement!");
    
    // PID soft-start: stabilize with neutral servo before enabling control
    moverAdelante(velocidadEstabilizacion);  // Start with stabilization speed
    estabilizacionInicio = millis();         // Start stabilization timer
    estadoActual = ESTABILIZANDO;            // Set to stabilization state
    integral = 0.0f; derivative = 0.0f; prevError = 0.0f;  // Reset PID terms
    Serial.println("System ready. Initial state: ESTABILIZANDO.");
}

// (Removed: reset handling with recalibration; reports and offset are reconfigured)

void actualizarMotorConRampa() {
    static unsigned long ultimoTiempoRampa = 0;      // Last ramp update time
    static DireccionMotor direccionRealMotor = MOTOR_DETENIDO;  // Actual motor direction
    const unsigned long INTERVALO_RAMPA_MS = 20;    // Ramp update interval
    const int ACELERACION = 15;                     // Acceleration rate per update
    const int DECELERACION = 25;                    // Deceleration rate per update

    unsigned long ahora = millis();
    if (ahora - ultimoTiempoRampa < INTERVALO_RAMPA_MS) {
        return; // Not time to update yet
    }
    ultimoTiempoRampa = ahora;

    // If we are stopped, we can accept the new direction immediately.
    if (velocidadActualMotor == 0) {
        direccionRealMotor = direccionMotor;
    }

    int objetivoActual = velocidadObjetivoMotor;
    // If a direction change is requested while moving, the priority objective is to stop.
    if (direccionMotor != direccionRealMotor && velocidadActualMotor > 0) {
        objetivoActual = 0;
    }

    // Acceleration/deceleration ramp logic
    if (velocidadActualMotor < objetivoActual) {
        velocidadActualMotor = min(objetivoActual, velocidadActualMotor + ACELERACION);  // Accelerate towards target
    } else if (velocidadActualMotor > objetivoActual) {
        velocidadActualMotor = max(objetivoActual, velocidadActualMotor - DECELERACION);  // Decelerate towards target
    }

    // Apply power and direction to H-Bridge
    switch (direccionRealMotor) {
        case MOTOR_ADELANTE:
            digitalWrite(ain2, LOW); digitalWrite(ain1, HIGH);  // Set forward direction
            analogWrite(pwma, velocidadActualMotor);            // Apply forward speed
            break;
        case MOTOR_ATRAS:
            digitalWrite(ain1, LOW); digitalWrite(ain2, HIGH);  // Set reverse direction
            analogWrite(pwma, velocidadActualMotor);            // Apply reverse speed
            break;
        case MOTOR_DETENIDO:
            digitalWrite(ain1, LOW); digitalWrite(ain2, LOW);   // Disable motor direction
            analogWrite(pwma, 0);                               // Set speed to zero
            velocidadActualMotor = 0; // Ensure speed is 0
            break;
    }
}

void loop() {
    if (estadoActual == DETENIDO) {
      detenerMotor(); // Ensure target is 0
      actualizarMotorConRampa();
      return; 
    }

    actualizarMotorConRampa();

    if (myIMU.hasReset()) {
      Serial.print("Sensor reset. Reconfiguring... ");
      setReports();   // Reconfigure IMU reports after reset
      offsetSet = false;  // Reset offset flag for recalibration
    }

    if (myIMU.dataAvailable()) {
        ultimoTiempoDatosImu = millis();  // Update IMU watchdog timer
        float qI = myIMU.getQuatI();      // Get quaternion I component
        float qJ = myIMU.getQuatJ();      // Get quaternion J component
        float qK = myIMU.getQuatK();      // Get quaternion K component
        float qReal = myIMU.getQuatReal(); // Get quaternion real component
        float siny_cosp = 2.0 * (qReal * qK + qI * qJ);  // Calculate yaw sine term
        float cosy_cosp = 1.0 - 2.0 * (qJ * qJ + qK * qK); // Calculate yaw cosine term
        float yaw = atan2(siny_cosp, cosy_cosp);  // Calculate yaw angle in radians
        float currentYawDegrees = yaw * 180.0 / M_PI;  // Convert to degrees
        if (!offsetSet) { yawOffset = currentYawDegrees; offsetSet = true; }  // Set initial offset
        float relativeYaw = currentYawDegrees - yawOffset;  // Calculate relative yaw
        if (relativeYaw > 180.0) { relativeYaw -= 360.0; }    // Normalize to [-180, 180]
        else if (relativeYaw < -180.0) { relativeYaw += 360.0; }
        currentYaw = -relativeYaw;  // Invert for robot coordinate system
    }
    
    bool leerSensoresAhora = false;
    if (estadoActual == NORMAL || estadoActual == PARKING || estadoActual == CORRIGIENDO) {
        leerSensoresAhora = true;  // Enable sensor reading for these states
    }

    if (leerSensoresAhora) {
#if USE_NEWPING
        servicioUltrasonidos();  // Handle asynchronous ultrasonic readings
#endif
        actualizarFiltrosSensores();  // Update sensor filters
    }

    actualizarControl();  // Update PID control and servo
    manejarEstados();     // Handle state machine logic

    static unsigned long lastPrintTime = 0;
    if (millis() - lastPrintTime > 300) {  // Print debug info every 300ms
        Serial.print("estado:"); Serial.print(estadoNombres[estadoActual]);  // Current state
        Serial.print("|Yaw:"); Serial.print(currentYaw, 1);                  // Current yaw angle
        Serial.print("|SetP:"); Serial.print(setpoint_actual_debug, 1);      // Current setpoint
        Serial.print("|Err:"); Serial.print(error, 1);                       // Current error
        Serial.print("|US_I:"); Serial.print(distanciaIzquierdoFiltrada, 0);  // Left ultrasonic
        Serial.print("|US_C:"); Serial.print(distanciaUltrasonicoCentro_dbg, 0);  // Center ultrasonic
        Serial.print("|US_D:"); Serial.print(distanciaDerechoFiltrada, 0);   // Right ultrasonic
        Serial.print("|curv:"); Serial.print(contadorCurvas);                // Turn counter
        Serial.print("|Srv:"); Serial.print(steeringServo.read());           // Servo position
        Serial.println();
        lastPrintTime = millis();
    }
}

void actualizarFiltrosSensores() {
     static bool leerIzquierdaEstaVez = true;  // Alternating flag for left/right sensor reading

     // Center: always measure for maximum front update frequency
     unsigned long ahoraMs = millis();
#if USE_NEWPING
     if (echoListo[SEN_CEN]) {  // Check if center echo is ready
         noInterrupts();        // Disable interrupts for atomic operation
         unsigned int us = echoUs[SEN_CEN];  // Get echo timing
         echoListo[SEN_CEN] = false;         // Mark echo as processed
         interrupts();          // Re-enable interrupts
         float dist = (us == 0) ? 999.9 : (float)us / US_ROUNDTRIP_CM; // NewPing factor cm
         if (dist < DISTANCIA_MIN_VALIDA || dist > DISTANCIA_MAX_VALIDA) dist = 999.9;  // Validate distance
         distanciaUltrasonicoCentro_dbg = dist;  // Store debug value
         lecturasCentro[indiceLecturaCentro] = dist;  // Add to filter buffer
         indiceLecturaCentro = (indiceLecturaCentro + 1) % FILTER_SIZE;  // Advance buffer index
     }
#else
     if (ahoraMs - ultimoPingCenMs >= MIN_INTERVALO_PING_MS) {  // Check minimum interval
         float lecturaRawCen = medirDistancia(TRIG_CENTRO, ECHO_CENTRO);  // Measure center distance
         distanciaUltrasonicoCentro_dbg = lecturaRawCen;                   // Store debug value
         lecturasCentro[indiceLecturaCentro] = lecturaRawCen;              // Add to filter buffer
         indiceLecturaCentro = (indiceLecturaCentro + 1) % FILTER_SIZE;   // Advance buffer index
         ultimoPingCenMs = ahoraMs;                                        // Update last ping time
     }
#endif

     if (leerIzquierdaEstaVez) {  // Read left sensor this cycle
         
#if USE_NEWPING
         if (echoListo[SEN_IZQ]) {  // Check if left echo is ready
             noInterrupts();        // Disable interrupts for atomic operation
             unsigned int us = echoUs[SEN_IZQ];  // Get echo timing
             echoListo[SEN_IZQ] = false;         // Mark echo as processed
             interrupts();          // Re-enable interrupts
             float dist = (us == 0) ? 999.9 : (float)us / US_ROUNDTRIP_CM;  // Convert to distance
             if (dist < DISTANCIA_MIN_VALIDA || dist > DISTANCIA_MAX_VALIDA) dist = 999.9;  // Validate
             lecturasIzquierdo[indiceLecturaIzquierdo] = dist;  // Add to filter buffer
             indiceLecturaIzquierdo = (indiceLecturaIzquierdo + 1) % FILTER_SIZE;  // Advance index
         }
#else
         if (ahoraMs - ultimoPingIzqMs >= MIN_INTERVALO_PING_MS) {  // Check minimum interval
             float lecturaRawIzq = medirDistancia(TRIG_IZQUIERDO, ECHO_IZQUIERDO);  // Measure left distance
             lecturasIzquierdo[indiceLecturaIzquierdo] = lecturaRawIzq;              // Add to buffer
             indiceLecturaIzquierdo = (indiceLecturaIzquierdo + 1) % FILTER_SIZE;   // Advance index
             ultimoPingIzqMs = ahoraMs;                                             // Update ping time
         }
#endif
     } else {  // Read right sensor this cycle
         
#if USE_NEWPING
         if (echoListo[SEN_DER]) {  // Check if right echo is ready
             noInterrupts();        // Disable interrupts for atomic operation
             unsigned int us = echoUs[SEN_DER];  // Get echo timing
             echoListo[SEN_DER] = false;         // Mark echo as processed
             interrupts();          // Re-enable interrupts
             float dist = (us == 0) ? 999.9 : (float)us / US_ROUNDTRIP_CM;  // Convert to distance
             if (dist < DISTANCIA_MIN_VALIDA || dist > DISTANCIA_MAX_VALIDA) dist = 999.9;  // Validate
             lecturasDerecho[indiceLecturaDerecho] = dist;  // Add to filter buffer
             indiceLecturaDerecho = (indiceLecturaDerecho + 1) % FILTER_SIZE;  // Advance index
         }
#else
         if (ahoraMs - ultimoPingDerMs >= MIN_INTERVALO_PING_MS) {  // Check minimum interval
             float lecturaRawDer = medirDistancia(TRIG_DERECHA, ECHO_DERECHA);  // Measure right distance
             lecturasDerecho[indiceLecturaDerecho] = lecturaRawDer;              // Add to buffer
             indiceLecturaDerecho = (indiceLecturaDerecho + 1) % FILTER_SIZE;   // Advance index
             ultimoPingDerMs = ahoraMs;                                          // Update ping time
         }
#endif
     }
     leerIzquierdaEstaVez = !leerIzquierdaEstaVez;  // Toggle for next cycle

#if FILTER_SIZE == 1
     // Fast path: no median when window is 1
     distanciaIzquierdoFiltrada = lecturasIzquierdo[indiceLecturaIzquierdo == 0 ? 0 : (indiceLecturaIzquierdo - 1) % FILTER_SIZE];
     distanciaCentroFiltrada   = lecturasCentro[indiceLecturaCentro == 0 ? 0 : (indiceLecturaCentro - 1) % FILTER_SIZE];
     distanciaDerechoFiltrada  = lecturasDerecho[indiceLecturaDerecho == 0 ? 0 : (indiceLecturaDerecho - 1) % FILTER_SIZE];
#else
     distanciaIzquierdoFiltrada = calcularMediana(lecturasIzquierdo, FILTER_SIZE);  // Apply median filter
     distanciaCentroFiltrada = calcularMediana(lecturasCentro, FILTER_SIZE);
     distanciaDerechoFiltrada = calcularMediana(lecturasDerecho, FILTER_SIZE);
#endif
}

void actualizarControl() {
    unsigned long currentTime = micros();
    unsigned long elapsedTime = currentTime - prevTimePID;

    if (estadoActual == ESTABILIZANDO) {
        steeringServo.write(servoNeutral);  // Keep servo neutral during stabilization
        integral = 0.0f; derivative = 0.0f; prevError = 0.0f;  // Reset PID terms
        setpoint_actual_debug = setpoint;
        return;
    }

    if (elapsedTime <= 0) elapsedTime = sampleInterval * 1000UL;  // Prevent division by zero
    dt_global = elapsedTime / 1000000.0f;  // Convert to seconds
    prevTimePID = currentTime;             // Update PID timing reference
    
    bool congelarPidYaw = (estadoActual == PARKING && subEstadoParkingActual == SUB_PARKING_ALINEACION_LATERAL && intentandoAlineacionLateralActual);  // Freeze yaw PID during lateral parking
    
    float kp_actual, ki_actual, kd_actual;
    float setpoint_actual;
    switch(estadoActual) {
        case NORMAL: 
            kp_actual = Kp; ki_actual = Ki; kd_actual = Kd; setpoint_actual = setpoint;  // Normal navigation PID
            break;
        case EN_MANIOBRA: 
            kp_actual = Kp_turn; ki_actual = Ki_turn; kd_actual = Kd_turn; setpoint_actual = targetSetpoint;  // Turn maneuver PID
            break;
        case CORRIGIENDO:
            kp_actual = Kp_stab; ki_actual = Ki_stab; kd_actual = Kd_stab; setpoint_actual = setpoint;  // Stabilization PID
            break;
        case PARKING:
            if (subEstadoParkingActual == SUB_PARKING_ALINEACION_FRONTAL || 
                (subEstadoParkingActual == SUB_PARKING_ALINEACION_LATERAL && !intentandoAlineacionLateralActual)) {
                kp_actual = Kp; ki_actual = Ki; kd_actual = Kd;  // Normal PID for front alignment or lateral yaw control
                setpoint_actual = setpoint;
            } else {
                kp_actual = 0; ki_actual = 0; kd_actual = 0;  // Disable yaw PID during lateral positioning  (erica no tenemos los bloques) 
                setpoint_actual = currentYaw;
            }
            break;
        default: detenerMotor(); return;
    }
    
    setpoint_actual_debug = setpoint_actual;
    error = calcularErrorAngular(setpoint_actual, currentYaw);  // Calculate angular error
    
    if (fabs(error) <= deadband) { error = 0.0f; }  // Apply deadband to prevent oscillation
    
    float integralAntes = integral;  // Store integral for anti-windup
    if (!congelarPidYaw) {
        integral += error * dt_global;  // Update integral term
        integral = constrain(integral, -integralLimit, integralLimit);  // Apply integral windup protection
        derivative = (dt_global > 0.0001f) ? (error - prevError) / dt_global : 0.0f;  // Calculate derivative
        prevError = error;  // Store error for next derivative calculation
    }
    
    pidOutput = (kp_actual * error) + (ki_actual * integral) + (kd_actual * derivative);  // Calculate PID output
    
    // Unsaturated command (for anti-windup)
    int servoCommandSinSat = servoNeutral;
    if (estadoActual == PARKING && subEstadoParkingActual == SUB_PARKING_ALINEACION_LATERAL && intentandoAlineacionLateralActual) {
        servoCommandSinSat -= pdOutputParkLat;  // Use lateral parking PD control
    } else if (!congelarPidYaw) { 
        servoCommandSinSat -= pidOutput;  // Use normal yaw PID control
    }
    
    int servoCommand = constrain(servoCommandSinSat, servoMinAngle, servoMaxAngle);  // Apply servo limits

    // Anti-windup: if saturated under yaw control, revert integration of this cycle
    bool controlYawActivo = !(estadoActual == PARKING && subEstadoParkingActual == SUB_PARKING_ALINEACION_LATERAL && intentandoAlineacionLateralActual) && !congelarPidYaw;
    if (controlYawActivo && servoCommand != servoCommandSinSat) {
        integral = integralAntes;  // Revert integral to prevent windup
        pidOutput = (kp_actual * error) + (ki_actual * integral) + (kd_actual * derivative);  // Recalculate PID
        servoCommandSinSat = servoNeutral - pidOutput;  // Recalculate servo command
        servoCommand = constrain(servoCommandSinSat, servoMinAngle, servoMaxAngle);  // Apply limits again
    }

    // Servo speed limiter (slew rate)
    static int servoPrevCommand = servoNeutral;
    const float servoMaxDegPerSec = 220.0f;  // Maximum servo speed in degrees per second
    float deltaMax = servoMaxDegPerSec * dt_global;  // Maximum change per update
    if (deltaMax < 1.0f) deltaMax = 1.0f;  // Minimum change of 1 degree
    int delta = servoCommand - servoPrevCommand;  // Calculate desired change
    if (delta > (int)deltaMax) {
        servoCommand = servoPrevCommand + (int)deltaMax;  // Limit positive change
    } else if (delta < -(int)deltaMax) {
        servoCommand = servoPrevCommand - (int)deltaMax;  // Limit negative change
    }

    steeringServo.write(servoCommand);  // Send command to servo
    servoPrevCommand = servoCommand;     // Store for next slew rate calculation
}

void manejarEstados() { 
    EstadoRobot estadoAnterior = estadoActual;  // Store previous state for change detection
    float umbralLat, umbralCen;                 // Dynamic thresholds for lateral and central detection
    bool aperturaIzquierda, aperturaDerecha, paredCercana;  // Detection flags
    unsigned long tiempoTranscurrido;           // Elapsed time variable
    switch (estadoActual) {
        case NORMAL: {
             moverAdelante(velocidadNormal);  // Set normal navigation speed
             
             if (distanciaCentralInicial < 999.0) {
                  umbralLat = distanciaCentralInicial * umbralRatioLateral;  // Dynamic lateral threshold
                  umbralCen = distanciaCentralInicial / umbralRatioCentral;  // Dynamic central threshold
             } else { umbralLat = 30.0; umbralCen = 25.0; }  // Default thresholds if no reference

             aperturaIzquierda = (distanciaIzquierdoFiltrada < 999.0 && distanciaIzquierdoFiltrada > umbralLat);  // Left opening detected
             aperturaDerecha   = (distanciaDerechoFiltrada < 999.0 && distanciaDerechoFiltrada > umbralLat);    // Right opening detected
             paredCercana      = (distanciaUltrasonicoCentro_dbg < 999.0 && distanciaUltrasonicoCentro_dbg < umbralCen);  // Wall ahead
             
             if (paredCercana) {  // Wall detected ahead
                  DireccionGiro direccionDetectadaActual = NINGUNA;
                  
                  // Condition 2: determine if there is a valid opening.
                  if (aperturaIzquierda && (!aperturaDerecha || distanciaIzquierdoFiltrada > distanciaDerechoFiltrada)) {
                      direccionDetectadaActual = IZQUIERDA;  // Prefer left if better or only option
                  } else if (aperturaDerecha) {
                      direccionDetectadaActual = DERECHA;    // Turn right if left not available
                  }

                  if (direccionDetectadaActual != NINGUNA) {
                       if (direccionPrimerGiro == NINGUNA) {
                            direccionPrimerGiro = direccionDetectadaActual; // Set direction on first turn   xd
                       }
                       
                       // Only turn if detected opening matches the first turn direction.
                       if (direccionPrimerGiro == direccionDetectadaActual) {
                            targetSetpoint = setpoint + (direccionPrimerGiro == IZQUIERDA ? -90.0f : 90.0f);  // Calculate turn target
                            
                            while (targetSetpoint <= -180.0f) targetSetpoint += 360.0f;  // Normalize angle
                            while (targetSetpoint > 180.0f) targetSetpoint -= 360.0f;
                            
                            integral = 0.0f; derivative = 0.0f;  // Reset PID terms for new maneuver
                            prevError = calcularErrorAngular(targetSetpoint, currentYaw);  // Initialize error
                            tiempoInicioManiobra = millis();     // Start maneuver timer
                            contadorCurvas++;                    // Increment turn counter
                            estadoActual = EN_MANIOBRA;          // Change to maneuver state
                       }
                  }
             }
             break;
        }

        case EN_MANIOBRA: {
             moverAdelante(velocidadGiro);  // Set turning speed
             tiempoTranscurrido = millis() - tiempoInicioManiobra;
             bool anguloAlcanzado = (fabs(error) < TURN_ANGLE_TOLERANCE);  // Check if turn angle reached
             bool tiempoManiobraTimeout = (tiempoTranscurrido >= TIMEOUT_MANIOBRA);  // Check timeout
             if (anguloAlcanzado || tiempoManiobraTimeout) {
                  setpoint = targetSetpoint;  // Update current setpoint
                  integral = 0.0f; 
                  derivative = 0.0f; 
                  prevError = 0.0f; 
                  estabilizacionInicio = millis();  // Start stabilization timer   xd
                  estadoActual = ESTABILIZANDO;     // Change to stabilization state
             }
             break;
        }

        case ESTABILIZANDO: {
             moverAdelante(velocidadEstabilizacion);  // Set stabilization speed
             bool tiempoEstabilizacionCumplido = (millis() - estabilizacionInicio >= tiempoEstabilizacion);  // Check stabilization time
             if (tiempoEstabilizacionCumplido) {
                  integral = 0.0f; derivative = 0.0f;  // Reset PID terms
                  prevError = calcularErrorAngular(setpoint, currentYaw);  // Initialize error for correction
                  correccionInicio = millis();          // Start correction timer
                  
                  estadoActual = CORRIGIENDO;          // Change to correction state
             }
             break;
        }

       case CORRIGIENDO: {
            int velocidadActualCorreccion;
            tiempoTranscurrido = millis() - correccionInicio;
            velocidadActualCorreccion = map(tiempoTranscurrido, 0, tiempoCorreccion, velocidadCorreccionMin, velocidadCorreccionMax);  // Ramp speed during correction
            moverAdelante(constrain(velocidadActualCorreccion, velocidadCorreccionMin, velocidadCorreccionMax));  // Apply ramped speed

            bool correccionEstableYaw = (fabs(error) < CORRECTION_ANGLE_TOLERANCE);  // Check yaw stability
            bool tiempoCorreccionCumplido = (tiempoTranscurrido >= tiempoCorreccion);  // Check correction time x
            bool timeoutCorreccionTotal = (tiempoTranscurrido >= TIMEOUT_CORRECCION);  // Check total timeout   d

            if ((correccionEstableYaw && tiempoCorreccionCumplido) || timeoutCorreccionTotal) {
                integral = 0.0f; derivative = 0.0f; prevError = error;  // Reset PID terms xd
                
                if (contadorCurvas >= NUM_CURVAS_ANTES_DE_PARAR) {
                    estadoActual = PARKING;                     // Start parking sequence
                    subEstadoParkingActual = SUB_PARKING_NO_INICIADO;
                    detenerMotor();                            // Stop motor for parking
                    steeringServo.write(servoNeutral);         // Center servo
                } else {
                    estadoActual = NORMAL;                     // Return to normal navigation
                }
            }
            break;
        }

        case PARKING: {
            float distActualParedObjetivo;  // Current distance to target wall
            float distObjetivoLateral;      // Target lateral distance

            if (subEstadoParkingActual == SUB_PARKING_NO_INICIADO) {
                subEstadoParkingActual = SUB_PARKING_ALINEACION_LATERAL;  // Start with lateral alignment
                intentandoAlineacionLateralActual = true;
                tiempoInicioIntentoActual = millis();
                tiempoInicioSubEstadoParking = millis();
                paredObjetivoParkingEsIzquierda = (direccionPrimerGiro == DERECHA);  // Determine target wall side
                errorParkLat = 0.0; prevErrorParkLat = 0.0; pdOutputParkLat = 0.0;  // Reset lateral parking PID
            }

            if (millis() - tiempoInicioSubEstadoParking > TIMEOUT_PARKING_SUBFASE) {
                subEstadoParkingActual = SUB_PARKING_ALINEACION_FRONTAL;  // Move to front alignment after timeout
                tiempoInicioSubEstadoParking = millis();
                detenerMotor(); 
                pdOutputParkLat = 0.0; 
                integral = 0.0f; 
            } else if (subEstadoParkingActual == SUB_PARKING_ALINEACION_LATERAL) { 
                if (millis() - tiempoInicioIntentoActual > intervalo) {
                    intentandoAlineacionLateralActual = !intentandoAlineacionLateralActual;  // Alternate between lateral and yaw control
                    tiempoInicioIntentoActual = millis();
                    detenerMotor();
                    if (intentandoAlineacionLateralActual) {
                        prevErrorParkLat = 0.0f;  // Reset lateral error for new attempt xd
                    } else {
                        integral = 0.0f;  // Reset yaw PID integral
                        prevError = calcularErrorAngular(setpoint, currentYaw);  // Initialize yaw error
                    }
                }

                if (intentandoAlineacionLateralActual) {
                    moverAdelante(VELOCIDAD_PARKING_ALINEACION_LATERAL);  // Move forward during lateral alignment
                    
                    if (paredObjetivoParkingEsIzquierda) {
                        distActualParedObjetivo = distanciaIzquierdoFiltrada;  // Use left sensor
                    } else {
                        distActualParedObjetivo = distanciaDerechoFiltrada;   // Use right sensor
                    }
                    if (direccionPrimerGiro == DERECHA) {
                        distObjetivoLateral = distanciaIzquierdoInicial;  // Target left wall distance
                    } else {
                        distObjetivoLateral = distanciaDerechoInicial;    // Target right wall distance
                    }

                    if (distActualParedObjetivo >= 999.0) {
                        intentandoAlineacionLateralActual = false;  // Switch to yaw control if no wall detected
                        tiempoInicioIntentoActual = millis();
                        integral = 0.0f;
                        prevError = calcularErrorAngular(setpoint, currentYaw);
                        detenerMotor();
                    } else {
                        errorParkLat = distObjetivoLateral - distActualParedObjetivo;  // Calculate lateral error
                        if (fabs(errorParkLat) < DEADBAND_PARKING_LATERAL) {
                            errorParkLat = 0.0f;  // Apply deadband
                        }
                        float derivParkLat = (dt_global > 0.0001f) ? (errorParkLat - prevErrorParkLat) / dt_global : 0.0f;  // Calculate derivative
                        pdOutputParkLat = (Kp_parking_lateral * errorParkLat) + (Kd_parking_lateral * derivParkLat);  // Calculate PD output
                        prevErrorParkLat = errorParkLat;
                        if (!paredObjetivoParkingEsIzquierda) { 
                            pdOutputParkLat *= -1.0f;  // Invert control for right wall xd
                        }

                        if (fabs(errorParkLat) < 2.0) {
                            subEstadoParkingActual = SUB_PARKING_ALINEACION_FRONTAL;  // Move to front alignment when close enough
                            tiempoInicioSubEstadoParking = millis(); 
                            detenerMotor(); 
                            pdOutputParkLat = 0.0; 
                            integral = 0.0f; 
                        }
                    }
                } else {
                    moverAdelante(VELOCIDAD_PARKING_ALINEACION_LATERAL);  // Continue moving during yaw control phase
                }
            } else if (subEstadoParkingActual == SUB_PARKING_ALINEACION_FRONTAL) {
                if (distanciaCentroFiltrada >= 999.0) {
                    detenerMotor(); steeringServo.write(servoNeutral);  // Stop if no front wall detected
                    estadoActual = DETENIDO;
                    subEstadoParkingActual = SUB_PARKING_FINALIZADO;
                } else {
                  float errorFrontal = distanciaCentroFiltrada - distanciaCentralInicial;  // Calculate front distance error

                  if (fabs(errorFrontal) < DISTANCIA_CENTRAL_OBJETIVO_TOLERANCIA_PARKING || (millis() - tiempoInicioSubEstadoParking > TIMEOUT_PARKING_SUBFASE)) {
                       detenerMotor(); steeringServo.write(servoNeutral);  // Stop when close enough or timeout
                       estadoActual = DETENIDO;
                       subEstadoParkingActual = SUB_PARKING_FINALIZADO;
                       digitalWrite(stby, LOW);  // Disable motor driver ericka no tenemos los bloques
                  } else if (errorFrontal > 0) {
                      int servoCommandForward = servoNeutral - pidOutput;  // Use normal PID for forward movement  erica se robaron la pista
                      steeringServo.write(constrain(servoCommandForward, servoMinAngle, servoMaxAngle));
                      moverAdelante(VELOCIDAD_PARKING_AVANCE);
                  } else {
                      int servoCommandBackward = servoNeutral + pidOutput;  // Invert PID for backward movement
                      steeringServo.write(constrain(servoCommandBackward, servoMinAngle, servoMaxAngle));
                      if (direccionMotor == MOTOR_ADELANTE && velocidadActualMotor > 0) {
                          detenerMotor();  // Stop forward movement before reversing
                      } else {
                          moverAtras(VELOCIDAD_PARKING_RETROCESO);  // Move backward
                      }
                  }
                }
            }
            break;
        }

        case DETENIDO: {
             detenerMotor();  // Ensure motor is stopped xd
             break;
        }
    }

    if (estadoActual != estadoAnterior) {
        Serial.print(">>> State change: ");
        Serial.print(estadoNombres[estadoAnterior]);
        Serial.print(" -> ");
        Serial.println(estadoNombres[estadoActual]);
    }
}
```

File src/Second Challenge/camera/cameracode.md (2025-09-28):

```py
# OpenMV H7 Computer Vision System for Autonomous Robot Navigation
# Advanced blob detection, tracking, and obstacle avoidance implementation
# This system provides real-time visual processing for robot navigation decisions
# Author: SETEKI 
# Version: 2.0 - Enhanced tracking and state machine implementation

import sensor      # Core camera sensor interface for image capture and processing
import time        # Time utilities for timing operations and delays
import pyb         # MicroPython board utilities for hardware control
import math        # Mathematical functions for geometric calculations
from pyb import LED # LED control interface for status indication

# =================================================================
# =========== MANUAL CONFIGURATION SECTION - 100% CUSTOMIZABLE ====
# =================================================================
# This section contains all configurable parameters for the vision system
# Each parameter can be tuned for optimal performance in different environments
# All values are empirically determined and can be adjusted based on testing

# --- 1. CAMERA SENSOR AND WINDOWING CONFIGURATION ---
# High definition sensor resolution provides maximum detail for blob detection
# HD resolution offers superior precision for obstacle identification at distance
SENSOR_RESOLUTION = sensor.HD  # High Definition: 1280x720 pixels for maximum precision
PIXEL_FORMAT = sensor.RGB565   # 16-bit color format balancing quality and processing speed
# Manual windowing crops the image to focus on the road surface area
# Format: (x_start, y_start, width, height) - focuses on lower portion of image
MANUAL_WINDOWING = (0, 300, 1280, 300)  # Crop to lower 300 pixels for road surface focus

# --- 2. OPTICAL LENS CORRECTION PARAMETERS ---
# Lens correction compensates for optical distortion in the camera lens
# Disabled by default but can be enabled for wide-angle lenses with distortion
ENABLE_LENS_CORRECTION = False  # Set to True if lens distortion correction is needed
LENS_STRENGTH = 1.8             # Correction strength factor (higher = more correction)
LENS_ZOOM = 1.0                 # Zoom factor for lens correction (1.0 = no zoom)

# --- 3. COLOR BLOB DETECTION THRESHOLDS AND PARAMETERS ---
# LAB color space thresholds for robust color detection under varying lighting
# LAB space provides better color consistency across different illumination conditions
# Format: [L_min, L_max, A_min, A_max, B_min, B_max] - L=lightness, A=green-red, B=blue-yellow
threshold_color_1 = (0, 100, 4, 127, -124, 127)    # Color 1: Red/Orange obstacles
threshold_color_2 = (0, 100, -128, -18, 11, 127)   # Color 2: Green obstacles  
threshold_color_3 = (0, 100, 8, 127, -128, 8)      # Color 3: Blue lane markers
color_thresholds = [threshold_color_1, threshold_color_2, threshold_color_3]
# Visualization colors for blob drawing (RGB format for display purposes)
blob_draw_colors = [(255, 0, 0), (0, 255, 0), (0, 0, 255)]  # Red, Green, Blue

# Blob detection filtering parameters to eliminate noise and false positives
BLOB_PIXELS_THRESHOLD = 1000   # Minimum pixel count for valid blob detection
BLOB_AREA_THRESHOLD = 1000     # Minimum area in pixels for blob validation

# Shape density filter to ensure detected blobs have solid, consistent shapes
# This eliminates fragmented or scattered pixel groups that aren't real obstacles
ENABLE_DENSITY_FILTER = True   # Enable density-based blob filtering
BLOB_DENSITY_THRESHOLD = 0.8   # Minimum density ratio (solid pixels / total area)

# --- 4. STATE MACHINE AND AVOIDANCE LOGIC CONFIGURATION ---
# Initial camera state for system startup and operation mode
ESTADO_INICIAL_CAMARA = "NORMAL_STREAMING"  # Default to continuous streaming mode
# Y-coordinate threshold for determining if obstacles are close enough to require avoidance
Y_PIXEL_THRESHOLD_FOR_CHECK = 125  # Pixels from bottom - closer obstacles trigger avoidance
# Duration for initial obstacle assessment phase in milliseconds
CHECK_STATE_DURATION_MS = 2000      # 2-second analysis period for obstacle counting
# Confidence threshold for lane marker detection during check phases
CHECK_CONFIDENCE_THRESHOLD = 0.4    # 40% confidence required for lane marker detection
# Confidence threshold for close obstacle detection during normal operation
CLOSE_BLOB_CONFIDENCE_THRESHOLD = 0.7  # 70% confidence for close obstacle detection

# --- 5. UART COMMUNICATION INTERFACE CONFIGURATION ---
# Serial communication setup for data transmission to main robot controller
# UART3 provides high-speed communication with 115200 baud rate
uart = pyb.UART(3, 115200, timeout_char=1000)  # 1-second timeout for robust communication

# --- 6. STATUS INDICATION LED CONFIGURATION ---
# Hardware LED control for visual status indication and debugging
led_red = LED(1)    # Red LED for error states and red blob detection
led_green = LED(2)  # Green LED for normal operation and green blob detection  
led_blue = LED(3)   # Blue LED for special states and blue lane marker detection

# --- 7. ADVANCED BLOB TRACKING SYSTEM PARAMETERS ---
# Multi-object tracking system for persistent obstacle monitoring
tracked_blobs = []                    # List of currently tracked blob objects
next_blob_id = 0                     # Unique identifier counter for new blob assignments
MATCHING_DISTANCE_THRESHOLD = 600    # Maximum pixel distance for blob association
FRAMES_UNSEEN_THRESHOLD = 15         # Frames before considering a blob lost

# =================================================================
# ==================== CONFIGURATION SECTION COMPLETE =============
# =================================================================

# =================================================================
# =========== AUXILIARY FUNCTIONS AND UTILITY CLASSES =============
# =================================================================
# These functions provide geometric calculations and coordinate transformations
# for blob position analysis and region-of-interest (ROI) determination
# The ROI system divides the camera view into strategic zones for navigation decisions

def get_section_from_coords(cx, cy, width):
    """
    Convert blob coordinates to a standardized section number for UART transmission.
    
    This function transforms 2D blob coordinates into a single section identifier
    that represents both horizontal (left/center/right) and vertical (upper/lower)
    position information. The section numbering follows a consistent 25-50-25
    horizontal division pattern for navigation coherence.
    
    Args:
        cx (int): Center X coordinate of the detected blob in pixels
        cy (int): Center Y coordinate of the detected blob in pixels  
        width (int): Total image width in pixels for coordinate normalization
        
    Returns:
        int: Section number (1-6) representing the blob's position:
             - Sections 1-3: Upper row (left, center, right)
             - Sections 4-6: Lower row (left, center, right)
    """
    col = get_roi_from_cx(cx, width)  # Use consistent 25-50-25 logic for coherence
    row = cy // (sensor.height() // 2)  # Determine upper (0) or lower (1) row
    return int((row * 3) + col + 1)  # Convert to 1-based section numbering

def get_roi_from_cx(cx, width):
    """
    Determine Region of Interest (ROI) based on blob's horizontal position.
    
    This function implements a strategic 25-50-25 horizontal division of the
    camera view. This division provides optimal coverage for navigation decisions:
    - Left/Right zones (25% each) for lateral obstacle detection
    - Center zone (50%) for primary navigation path monitoring
    
    The ROI system enables different avoidance strategies based on obstacle
    position, allowing the robot to make context-aware navigation decisions.
    
    Args:
        cx (int): Center X coordinate of the detected blob in pixels
        width (int): Total image width in pixels for boundary calculations
        
    Returns:
        int: ROI index representing horizontal position:
             - 0: Left region (0% to 25% of image width)
             - 1: Center region (25% to 75% of image width) 
             - 2: Right region (75% to 100% of image width)
    """
    # Strategic division: Laterals 25% each, Center 50% for optimal navigation coverage
    if cx < width / 4:
        return 0  # Left region - obstacles here require left avoidance maneuvers
    elif cx < (width * 3) / 4:
        return 1  # Center region - obstacles here require primary avoidance strategies
    else:
        return 2  # Right region - obstacles here require right avoidance maneuvers

# =================================================================
# =========== CAMERA SENSOR INITIALIZATION AND CONFIGURATION ======
# =================================================================
# Complete camera sensor setup with optimal parameters for vision processing
# This initialization sequence ensures consistent image quality and processing speed
# All settings are configured for maximum blob detection accuracy and reliability

# Reset camera sensor to default state and clear any previous configuration
sensor.reset()
# Set pixel format to RGB565 for optimal balance between color accuracy and processing speed
sensor.set_pixformat(PIXEL_FORMAT)
# Configure sensor resolution to HD for maximum detail and precision in blob detection
sensor.set_framesize(SENSOR_RESOLUTION)
# Apply manual windowing to crop image and focus on relevant road surface area
if MANUAL_WINDOWING: sensor.set_windowing(MANUAL_WINDOWING)
# Skip initial frames to allow sensor stabilization and achieve consistent exposure
sensor.skip_frames(time=2000)  # 2-second stabilization period for optimal image quality
# Disable automatic gain control to maintain consistent blob detection thresholds
sensor.set_auto_gain(False)    # Manual gain control prevents exposure variations
# Disable automatic white balance to ensure consistent color detection across lighting
sensor.set_auto_whitebal(False)  # Manual white balance maintains color threshold reliability
# Initialize timing clock for frame rate monitoring and performance analysis
clock = time.clock()

# =================================================================
# =========== GLOBAL STATE VARIABLES AND SYSTEM STATUS ============
# =================================================================
# These variables manage the system's operational state and tracking information
# State management enables different processing modes and communication protocols

# Camera operational state - determines current processing mode and behavior
estado_camara = ESTADO_INICIAL_CAMARA  # Initialize to normal streaming mode
# Maximum number of obstacles that can be avoided in current navigation segment
bloques_a_esquivar_max = 0  # Starts at 0, defined during CHECK phases based on analysis
# Current count of obstacles successfully avoided in this navigation segment
bloques_esquivados_actualmente = 0  # Tracks avoidance progress for limit enforcement
# Flag controlling UART data transmission to main robot controller
streaming_habilitado = False  # Disabled until CHECK phase completion enables streaming
# Type of CHECK analysis being performed (INITIAL or NORMAL)
check_type = ""  # Determines analysis methodology and decision criteria
# ROI masking mode for selective vision processing (FULL, IGNORE_LEFT, IGNORE_RIGHT)
roi_mask_mode = "FULL"  # NEW: Controls vision mask for directional obstacle filtering

print("Camera configuration completed. Initializing multifunction main loop...")

# =================================================================
# =========== SYSTEM STARTUP INDICATION AND STATUS SEQUENCE =======
# =================================================================
# Visual startup sequence provides immediate feedback about system initialization
# LED patterns indicate successful boot and readiness for operation

# Illuminate all LEDs simultaneously to create white light indicating script execution
# This provides immediate visual confirmation that the system is starting up
led_red.on()    # Red LED component for white light indication
led_green.on()  # Green LED component for white light indication
led_blue.on()   # Blue LED component for white light indication
time.sleep_ms(1000)  # 1-second white light display for startup confirmation
# Turn off all LEDs to prepare for operational status indication
led_red.off()
led_green.off()
led_blue.off()

# Green LED blinking sequence indicates successful initialization completion
# Three rapid blinks provide clear visual confirmation of proper startup
for _ in range(3):
    led_green.on()    # Illuminate green LED for successful status indication
    time.sleep_ms(100)  # 100ms ON duration for visible blink
    led_green.off()   # Turn off green LED
    time.sleep_ms(100)  # 100ms OFF duration for clear blink separation

# =================================================================
# =========== MAIN PROCESSING LOOP - CONTINUOUS VISION OPERATION ====
# =================================================================
# The main loop provides continuous image processing and communication handling
# This loop manages multiple operational states and real-time decision making
# All vision processing, blob tracking, and UART communication occurs here

while True:
    # Update frame timing for performance monitoring and frame rate calculation
    clock.tick()  # Increment frame counter and calculate processing timing
    
    # Default LED status indication - green LED shows normal operation
    # LED states provide immediate visual feedback about system status
    led_red.off()    # Red LED off during normal operation
    led_green.on()   # Green LED on indicates system running normally
    led_blue.off()   # Blue LED off during normal operation

    # =================================================================
    # =========== UART COMMUNICATION PROTOCOL HANDLING =================
    # =================================================================
    # Process incoming commands from main robot controller via UART
    # Command protocol enables dynamic system behavior and state transitions
    # Each command triggers specific processing modes or parameter changes
    
    if uart.any():  # Check for incoming UART data availability
        comando = uart.read(1)  # Read single byte command from robot controller
        print(f"UART data received: {comando}")
        
        # Command '2': Initialize INITIAL CHECK phase for obstacle assessment
        if comando == b'2':
            print("Command '2' received. Preparing INITIAL CHECK.")
            estado_camara = "CHECK"      # Switch to CHECK processing mode
            check_type = "INITIAL"       # Set analysis type to initial assessment
            
        # Command '1': Initialize NORMAL CHECK phase for ongoing obstacle monitoring
        elif comando == b'1':
            print("Command '1' received. Preparing NORMAL CHECK.")
            estado_camara = "CHECK"      # Switch to CHECK processing mode
            check_type = "NORMAL"        # Set analysis type to normal monitoring
            
        # Command '3': Activate wall confirmation analysis for navigation decisions
        elif comando == b'3':
            print("Command '3' received. Preparing CONFIRM WALL.")
            estado_camara = "CONFIRM_WALL"  # Switch to wall confirmation mode
            
        # Command 'R': Set ROI mask to ignore left side obstacles (right turn preparation)
        elif comando == b'R':
            print("Command 'R' received. MASK: Ignoring Left side.")
            roi_mask_mode = "IGNORE_LEFT"  # Mask left region for right-turn scenarios
            
        # Command 'L': Set ROI mask to ignore right side obstacles (left turn preparation)  
        elif comando == b'L':
            print("Command 'L' received. MASK: Ignoring Right side.")
            roi_mask_mode = "IGNORE_RIGHT"  # Mask right region for left-turn scenarios
            
        # Command 'N': Reset ROI mask to full vision (normal navigation mode)
        elif comando == b'N':
            print("Command 'N' received. MASK: Full Vision enabled.")
            roi_mask_mode = "FULL"  # Enable full field of view for normal operation

    # =================================================================
    # =========== WALL CONFIRMATION STATE - OBSTACLE TYPE ANALYSIS =====
    # =================================================================
    # This state performs single-frame analysis to distinguish between walls and obstacles
    # Critical for navigation decisions - determines if robot should turn or continue straight
    # Analysis focuses on center region to avoid false positives from lateral obstacles
    
    if estado_camara == "CONFIRM_WALL":
        # LED indication: Yellow (red+green) indicates wall confirmation analysis in progress
        led_red.on()    # Red LED component for yellow indication
        led_green.on()  # Green LED component for yellow indication  
        led_blue.off()  # Blue LED off during wall confirmation

        print("Analyzing image for wall confirmation...")
        # Capture single frame for wall confirmation analysis
        img = sensor.snapshot()

        # Initialize detection flag for center region obstacle analysis
        blob_found_in_center = False
        
        # Search for obstacle blobs (colors 0 and 1) across entire image
        # These colors represent red and green obstacles that require avoidance
        for i in range(2):  # Analyze first two color thresholds (obstacle colors)
            # Find all blobs matching current color threshold with filtering applied
            all_blobs = img.find_blobs([color_thresholds[i]], 
                                     pixels_threshold=BLOB_PIXELS_THRESHOLD, 
                                     area_threshold=BLOB_AREA_THRESHOLD, 
                                     merge=True)  # Merge overlapping detections
            
            # Apply density filtering to eliminate fragmented or scattered pixel groups
            blobs_found = [b for b in all_blobs if b.density() > BLOB_DENSITY_THRESHOLD] if ENABLE_DENSITY_FILTER else all_blobs

            # Filter blobs to only those located in the center region (ROI index 1)
            # Center region analysis provides most reliable wall vs obstacle distinction
            for b in blobs_found:
                if get_roi_from_cx(b.cx(), img.width()) == 1:  # 1 is center region index
                    blob_found_in_center = True
                    # Draw red rectangle around detected obstacle for visual confirmation
                    img.draw_rectangle(b.rect(), color=(255, 0, 0))  # Red visualization
                    print(f"Obstacle blob found in center section! Color index: {i}")
                    break  # Exit blob analysis loop once center obstacle found
            if blob_found_in_center:
                break  # Exit color analysis loop once obstacle confirmed

        # Decision logic: Send appropriate response based on center region analysis
        if blob_found_in_center:
            # Obstacle detected in center - this is NOT a wall, robot must avoid
            print("Result: Close obstacle detected. Sending 'P,8'.")
            uart.write("P,8\r\n")  # Signal: Obstacle requiring avoidance maneuver
        else:
            # No obstacles in center region - this is a wall or distant obstacle
            print("Result: Wall detected (or distant obstacle ignored). Sending 'P,9'.")
            uart.write("P,9\r\n")  # Signal: Wall - robot can proceed or turn

        # Return to normal streaming state and restart loop to avoid further processing
        estado_camara = "NORMAL_STREAMING"
        continue  # Skip remaining processing for this frame

    # =================================================================
    # =========== CHECK STATE - OBSTACLE ASSESSMENT AND ANALYSIS ========
    # =================================================================
    # CHECK state performs comprehensive obstacle analysis to determine avoidance limits
    # Two types of CHECK analysis: INITIAL (startup assessment) and NORMAL (ongoing monitoring)
    # Analysis results determine maximum number of obstacles robot can avoid in current segment
    
    if estado_camara == "CHECK":
        # =================================================================
        # =========== INITIAL CHECK - STARTUP OBSTACLE ASSESSMENT ==========
        # =================================================================
        # INITIAL CHECK analyzes the environment at robot startup to set avoidance limits
        # This prevents the robot from attempting to avoid too many obstacles in unknown terrain
        # Analysis focuses on center region to identify immediate navigation challenges
        
        if check_type == "INITIAL":
            # LED indication: Blue LED indicates INITIAL CHECK analysis in progress
            led_blue.on()   # Blue LED for INITIAL CHECK status indication
            led_green.off() # Green LED off during CHECK analysis

            print(f"Starting INITIAL analysis for {CHECK_STATE_DURATION_MS} ms...")
            # Initialize timing for analysis duration control
            start_time = time.ticks_ms()
            # Flag to track if any obstacles are detected during analysis period
            initial_blob_found = False
            # Time-based analysis loop - runs for specified duration to assess environment
            while time.ticks_diff(time.ticks_ms(), start_time) < CHECK_STATE_DURATION_MS:
                # Capture current frame for obstacle analysis
                img = sensor.snapshot()
                
                # Search for obstacle blobs (colors 0 and 1) representing red and green obstacles
                # These are the primary obstacles that require avoidance maneuvers
                for i in range(2):  # Analyze first two color thresholds (obstacle colors)
                    # Find all blobs matching current color with filtering parameters
                    all_blobs = img.find_blobs([color_thresholds[i]], 
                                             pixels_threshold=BLOB_PIXELS_THRESHOLD, 
                                             area_threshold=BLOB_AREA_THRESHOLD, 
                                             merge=True)  # Merge overlapping detections
                    
                    # Apply density filtering to ensure detected blobs are solid obstacles
                    blobs_found = [b for b in all_blobs if b.density() > BLOB_DENSITY_THRESHOLD] if ENABLE_DENSITY_FILTER else all_blobs
                    
                    # Filter blobs to only those in center region for reliable obstacle assessment
                    # Center region provides most accurate indication of immediate navigation challenges
                    for b in blobs_found:
                        if get_roi_from_cx(b.cx(), img.width()) == 1:  # Center region check
                            initial_blob_found = True
                            break  # Exit blob analysis once obstacle found
                    if initial_blob_found:
                        break  # Exit color analysis loop once obstacle confirmed

            print("INITIAL analysis completed.")
            
            # Set avoidance limit based on analysis results
            if initial_blob_found:
                # Obstacle detected - allow maximum 1 avoidance maneuver for safety
                bloques_a_esquivar_max = 1
                print("INITIAL CHECK result: Will avoid MAXIMUM 1 obstacle.")
            else:
                # No obstacles detected - no avoidance maneuvers needed
                bloques_a_esquivar_max = 0
                print("INITIAL CHECK result: Will avoid 0 obstacles.")

            # Send response to robot controller in format: C,{lane_markers}
            # For INITIAL CHECK, lane markers don't apply, so send 0
            respuesta = "C,0\r\n"
            uart.write(respuesta)
            print(f"Sending INITIAL CHECK: {respuesta.strip()} (Internal limit: {bloques_a_esquivar_max})")
            
            # Enable UART data streaming after successful CHECK completion
            streaming_habilitado = True
            print("UART data streaming ENABLED.")

        # =================================================================
        # =========== NORMAL CHECK - ONGOING OBSTACLE MONITORING ===========
        # =================================================================
        # NORMAL CHECK performs comprehensive analysis during robot operation
        # This analysis determines both obstacle avoidance limits and lane marker presence
        # More sophisticated than INITIAL CHECK, includes confidence-based decision making
        
        elif check_type == "NORMAL":
            # LED indication: Green LED indicates NORMAL CHECK analysis in progress
            led_green.on()  # Green LED for NORMAL CHECK status indication

            # =================================================================
            # =========== ROBUST ANALYSIS LOGIC FOR NORMAL OPERATION ==========
            # =================================================================
            # Initialize timing and analysis counters for comprehensive assessment
            start_time = time.ticks_ms()
            frames_analyzed = 0           # Total frames processed during analysis
            third_color_detections = 0    # Count of blue lane marker detections
            close_blob_detections = 0     # Count of close obstacle detections

            print(f"Starting NORMAL analysis for {CHECK_STATE_DURATION_MS} ms...")

            while time.ticks_diff(time.ticks_ms(), start_time) < CHECK_STATE_DURATION_MS:
                img = sensor.snapshot()
                frames_analyzed += 1
                frame_had_close_blob = False

                # 1. Analizar si hay bloques CERCANOS (colores 1 y 2) en la sección central
                for i in range(2):
                    all_blobs = img.find_blobs([color_thresholds[i]], pixels_threshold=BLOB_PIXELS_THRESHOLD, area_threshold=BLOB_AREA_THRESHOLD, merge=True)
                    blobs_found = [b for b in all_blobs if b.density() > BLOB_DENSITY_THRESHOLD] if ENABLE_DENSITY_FILTER else all_blobs
                    for b in blobs_found:
                        # Comprobar si está cerca Y en el centro
                        if (b.y() + b.h()) > Y_PIXEL_THRESHOLD_FOR_CHECK and get_roi_from_cx(b.cx(), img.width()) == 1:
                            frame_had_close_blob = True
                            break
                    if frame_had_close_blob:
                        break

                if frame_had_close_blob:
                    close_blob_detections += 1

                # 2. Contar si el tercer color está presente en la sección central
                all_blobs_c3 = img.find_blobs([color_thresholds[2]], pixels_threshold=BLOB_PIXELS_THRESHOLD, area_threshold=BLOB_AREA_THRESHOLD, merge=True)
                # Filtrar por densidad Y por estar en el centro
                blobs_in_center_c3 = [b for b in all_blobs_c3 if get_roi_from_cx(b.cx(), img.width()) == 1]
                if any(b.density() > BLOB_DENSITY_THRESHOLD for b in blobs_in_center_c3) if ENABLE_DENSITY_FILTER else blobs_in_center_c3:
                    third_color_detections += 1

            print(f"Análisis NORMAL completado. Detecciones Bloque Cercano: {close_blob_detections}.")

            # --- TOMAR DECISIONES BASADAS EN EL ANÁLISIS ---
            close_blob_confidence = close_blob_detections / frames_analyzed if frames_analyzed > 0 else 0
            if close_blob_confidence > CLOSE_BLOB_CONFIDENCE_THRESHOLD:
                bloques_a_esquivar_max = 2
                print(f"Resultado CHECK NORMAL: Se esquivarán 2 (Confianza: {close_blob_confidence:.2f}).")
            else:
                bloques_a_esquivar_max = 1
                print(f"Resultado CHECK NORMAL: Se esquivará 1 (Confianza: {close_blob_confidence:.2f}).")

            third_color_confidence = third_color_detections / frames_analyzed if frames_analyzed > 0 else 0
            tercer_umbral_presente = third_color_confidence > CHECK_CONFIDENCE_THRESHOLD
            if tercer_umbral_presente:
                print(f"Resultado CHECK: Marcas de carril presentes (Confianza: {third_color_confidence:.2f})")
            else:
                print(f"Resultado CHECK: Marcas de carril ausentes (Confianza: {third_color_confidence:.2f})")

            marcas_presentes_int = 1 if tercer_umbral_presente else 0
            respuesta = f"C,{marcas_presentes_int}\r\n"
            uart.write(respuesta)
            print(f"Enviando CHECK NORMAL: {respuesta.strip()} (Límite interno: {bloques_a_esquivar_max})")

        # Reiniciar variables para el siguiente tramo
        bloques_esquivados_actualmente = 0
        tracked_blobs = []
        estado_camara = "NORMAL_STREAMING"
        continue

    # --- LÓGICA DE PROCESAMIENTO DE IMAGEN Y VISUALIZACIÓN (SIEMPRE ACTIVA) ---
    img = sensor.snapshot()
    if ENABLE_LENS_CORRECTION:
        img.lens_corr(strength=LENS_STRENGTH, zoom=LENS_ZOOM)

    # =================================================================
    # =========== ADVANCED BLOB TRACKING SYSTEM WITH PREDICTION ==========
    # =================================================================
    # Multi-object tracking system with velocity prediction and association
    # Implements simplified Kalman filter approach for robust obstacle tracking
    # System maintains persistent tracking across frames for reliable navigation decisions

    # =================================================================
    # =========== STEP 1: VELOCITY-BASED POSITION PREDICTION ============
    # =================================================================
    # Predict new positions of currently tracked blobs based on their velocity vectors
    # This prediction improves association accuracy and handles temporary occlusions
    # Prediction step occurs before new blob detection for optimal matching
    
    for tb in tracked_blobs:
        # Update predicted position using stored velocity components
        tb['cx'] += tb['vx']  # Predict new X coordinate based on X velocity
        tb['cy'] += tb['vy']  # Predict new Y coordinate based on Y velocity
        # Note: Rectangle coordinates are only updated on actual detection matches
        # This keeps prediction lightweight while maintaining tracking accuracy

    # =================================================================
    # =========== STEP 2: ADAPTIVE BLOB DETECTION WITH ROI FILTERING ======
    # =================================================================
    # Detect new blobs in current frame with adaptive region-of-interest filtering
    # ROI masking allows selective obstacle detection based on navigation context
    # Detection focuses on obstacle colors (red and green) for avoidance decisions
    
    # Initialize full image search region
    search_roi = (0, 0, img.width(), img.height())
    img_width = img.width()
    img_height = img.height()

    # Apply ROI masking based on navigation context for selective detection
    if roi_mask_mode == "IGNORE_LEFT":
        # Mask left region for right-turn preparation scenarios
        roi_x = img_width // 4
        search_roi = (roi_x, 0, img_width - roi_x, img_height)
        # Draw yellow debug line to visualize masked region
        img.draw_line(roi_x, 0, roi_x, img_height, color=(255, 255, 0))
    elif roi_mask_mode == "IGNORE_RIGHT":
        # Mask right region for left-turn preparation scenarios
        roi_w = (img_width * 3) // 4
        search_roi = (0, 0, roi_w, img_height)
        # Draw yellow debug line to visualize masked region
        img.draw_line(roi_w, 0, roi_w, img_height, color=(255, 255, 0))

    # Initialize detection storage for current frame analysis
    all_detections_this_frame = []
    
    # Detect blobs for obstacle colors only (colors 0 and 1: red and green)
    for i, current_threshold in enumerate(color_thresholds[:2]):  # Only obstacle colors
        # Find blobs matching current color threshold with filtering parameters
        blobs_of_color = img.find_blobs([current_threshold], 
                                      pixels_threshold=BLOB_PIXELS_THRESHOLD, 
                                      area_threshold=BLOB_AREA_THRESHOLD, 
                                      merge=True,      # Merge overlapping detections
                                      margin=10,       # Margin for blob merging
                                      roi=search_roi)  # Apply ROI filtering

        # Apply density filtering to eliminate fragmented or scattered pixel groups
        filtered_blobs = [b for b in blobs_of_color if b.density() > BLOB_DENSITY_THRESHOLD] if ENABLE_DENSITY_FILTER else blobs_of_color

        # Store detected blobs with color index for tracking association
        for blob in filtered_blobs:
            all_detections_this_frame.append({'blob': blob, 'color_index': i})

    # =================================================================
    # =========== STEP 3: NEAREST NEIGHBOR ASSOCIATION AND UPDATE ========
    # =================================================================
    # Associate detected blobs with existing tracked blobs using distance-based matching
    # Implements simplified Kalman filter correction for velocity estimation
    # Association prevents duplicate tracking and maintains blob identity across frames
    
    # Reset matching flags for all tracked blobs
    for tracked_blob in tracked_blobs:
        tracked_blob['matched'] = False

    # Perform nearest neighbor association for each tracked blob
    for tracked_blob in tracked_blobs:
        best_match = None
        min_dist_sq = MATCHING_DISTANCE_THRESHOLD**2  # Maximum association distance squared

        # Find closest matching detection of same color type
        for detection in all_detections_this_frame:
            # Match only blobs of same color and not already matched
            if tracked_blob['color_index'] == detection['color_index'] and not detection.get('matched', False):
                # Calculate distance squared between predicted position and actual detection
                # Distance calculation uses PREDICTED position for improved association accuracy
                dist_sq = (tracked_blob['cx'] - detection['blob'].cx())**2 + (tracked_blob['cy'] - detection['blob'].cy())**2
                if dist_sq < min_dist_sq:
                    min_dist_sq = dist_sq
                    best_match = detection

        # Update tracked blob with best match if found
        if best_match:
            new_blob = best_match['blob']
            
            # Velocity correction using simplified Kalman filter approach
            # Correct velocity based on difference between prediction and actual detection
            # This is a simplified form of Kalman filter correction for smooth tracking
            # Factor of 0.5 provides balanced tracking with smooth velocity updates
            tracked_blob['vx'] = int((tracked_blob['vx'] * 0.5) + ((new_blob.cx() - tracked_blob['cx']) * 0.5))
            tracked_blob['vy'] = int((tracked_blob['vy'] * 0.5) + ((new_blob.cy() - tracked_blob['cy']) * 0.5))

            # Update position to actual detected coordinates
            tracked_blob['cx'] = new_blob.cx()      # Update X coordinate to detected position
            tracked_blob['cy'] = new_blob.cy()      # Update Y coordinate to detected position
            tracked_blob['rect'] = new_blob.rect()  # Update bounding rectangle
            tracked_blob['frames_unseen'] = 0       # Reset unseen frame counter
            tracked_blob['matched'] = True          # Mark as successfully matched
            best_match['matched'] = True            # Mark detection as used

    # =================================================================
    # =========== STEP 4: LOST BLOB MANAGEMENT AND CLEANUP ===============
    # =================================================================
    # Manage tracked blobs that were not detected in current frame
    # Remove blobs that are lost (too many unseen frames) or have passed the robot
    # Count successfully avoided obstacles for navigation limit enforcement
    
    blobs_to_remove = []
    for tracked_blob in tracked_blobs:
        # Increment unseen counter for unmatched blobs
        if not tracked_blob['matched']:
            tracked_blob['frames_unseen'] += 1

        # Determine if blob should be removed from tracking
        is_lost = tracked_blob['frames_unseen'] > FRAMES_UNSEEN_THRESHOLD  # Too many unseen frames
        is_passed = tracked_blob['cy'] > (sensor.height() * 0.9)          # Blob passed robot (bottom 10%)

        # Remove blob if lost or passed, and count as avoided obstacle
        if is_lost or is_passed:
            blobs_to_remove.append(tracked_blob)
            # Count obstacle avoidance for navigation limit tracking
            if tracked_blob['color_index'] < 2:  # Only count obstacle colors (0, 1)
                bloques_esquivados_actualmente += 1
                print(f"OBSTACLE AVOIDED (ID: {tracked_blob['id']}). Total: {bloques_esquivados_actualmente}")

    # Remove lost/passed blobs from tracking list
    if blobs_to_remove:
        tracked_blobs = [b for b in tracked_blobs if b not in blobs_to_remove]

    # =================================================================
    # =========== STEP 5: NEW BLOB INITIALIZATION AND TRACKING ==========
    # =================================================================
    # Create new tracked blob objects for unmatched detections
    # Initialize new blobs with zero velocity and assign unique IDs
    # This handles newly appeared obstacles that weren't previously tracked
    
    for detection in all_detections_this_frame:
        # Process only detections that weren't matched to existing tracked blobs
        if not detection.get('matched', False):
            new_blob = detection['blob']
            # Create new tracked blob object with initial parameters
            new_tracked_blob = {
                'id': next_blob_id,                    # Assign unique identifier
                'cx': new_blob.cx(),                   # Set initial X coordinate
                'cy': new_blob.cy(),                   # Set initial Y coordinate
                'vx': 0,                              # Initialize X velocity to zero
                'vy': 0,                              # Initialize Y velocity to zero
                'rect': new_blob.rect(),              # Store bounding rectangle
                'color_index': detection['color_index'], # Store color classification
                'matched': True,                      # Mark as matched in this frame
                'frames_unseen': 0                    # Initialize unseen counter
            }
            tracked_blobs.append(new_tracked_blob)     # Add to tracking list
            next_blob_id += 1                          # Increment ID counter for next blob

    # =================================================================
    # =========== BLOB TRACKING SYSTEM COMPLETION =====================
    # =================================================================
    # Advanced multi-object tracking system now complete
    # System provides persistent obstacle tracking with velocity prediction
    # Ready for navigation decision making and UART communication

    # =================================================================
    # =========== CLOSEST OBSTACLE SELECTION FOR NAVIGATION ==============
    # =================================================================
    # Select the closest obstacle blob for navigation decision making
    # Closest blob is determined by lowest Y coordinate (bottom of bounding box)
    # Only obstacle colors (0, 1) are considered for avoidance decisions
    
    # Filter tracked blobs to only obstacle colors (red and green)
    candidate_blobs = [b for b in tracked_blobs if b['color_index'] < 2]
    closest_blob = None
    
    # Find closest obstacle based on bottom edge position (Y + height)
    if candidate_blobs:
        # Select blob with maximum bottom edge position (closest to robot)
        closest_blob = max(candidate_blobs, key=lambda b: b['rect'][1] + b['rect'][3])

    # =================================================================
    # =========== VISUALIZATION AND DEBUG DISPLAY ======================
    # =================================================================
    # Draw visual indicators for all tracked blobs with status information
    # Provides real-time visual feedback for debugging and monitoring
    
    for tb in tracked_blobs:
        # Draw colored rectangle around each tracked blob based on color classification
        img.draw_rectangle(tb['rect'], color=blob_draw_colors[tb['color_index']])
        # Display blob ID above the rectangle for tracking identification
        img.draw_string(tb['rect'][0], tb['rect'][1] - 10, f"ID:{tb['id']}", color=(255,255,0))
        # Show unseen frame count for unmatched blobs (red text)
        if not tb['matched']:
            img.draw_string(tb['rect'][0], tb['rect'][1] + 10, f"U:{tb['frames_unseen']}", color=(255,0,0))

    # =================================================================
    # =========== NAVIGATION DECISION LOGIC AND UART MESSAGE GENERATION ===
    # =================================================================
    # Determine if closest obstacle should be reported to robot controller
    # Apply avoidance limits and color-based reporting rules for navigation decisions
    # Generate UART message with obstacle position and region information
    
    # Initialize default UART message values (no obstacle detected)
    blob_sect_str = "0"  # Default: no obstacle section
    blob_roi_str = "0"   # Default: no obstacle region

    # Check if obstacle should be reported based on avoidance limits and detection
    if bloques_esquivados_actualmente < bloques_a_esquivar_max and closest_blob:
        # Calculate ROI (0, 1, 2) and color index for avoidance logic
        roi = get_roi_from_cx(closest_blob['cx'], img.width())
        color_index = closest_blob['color_index']

        # Apply color-based reporting rules for strategic obstacle avoidance:
        # - Red obstacles (0): Report only if in center (1) or right (2) regions
        # - Green obstacles (1): Report only if in left (0) or center (1) regions
        # This prevents unnecessary avoidance maneuvers for obstacles on opposite sides
        if (color_index == 0 and roi > 0) or \
           (color_index == 1 and roi < 2):

            # Calculate obstacle section with color offset for UART transmission
            y_coord = closest_blob['rect'][1] + closest_blob['rect'][3]  # Bottom edge coordinate
            section = get_section_from_coords(closest_blob['cx'], y_coord, img.width())
            section_with_offset = section + (color_index * 6)  # Add color-based offset

            # Prepare UART message components
            blob_sect_str = str(section_with_offset)  # Convert section to string
            blob_roi_str = str(roi)                   # Convert ROI to string

            # Update LED indication to show detected obstacle color
            # Turn off default green LED to show specific obstacle color
            led_green.off()
            if color_index == 0:
                led_red.on()      # Red LED for red obstacle detection
            elif color_index == 1:
                led_green.on()    # Green LED for green obstacle detection (override default)

    # Generate final UART message with obstacle information
    mensaje_final = f"B,{blob_sect_str},{blob_roi_str}\r\n"
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

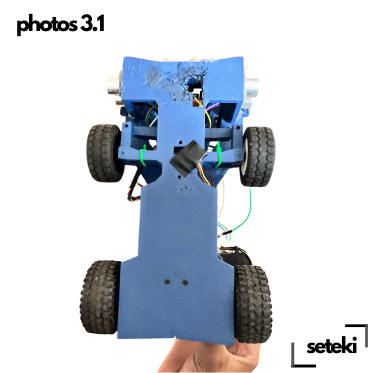
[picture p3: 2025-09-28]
robot photos/3.1 (National)/3.1 Photos (10).png

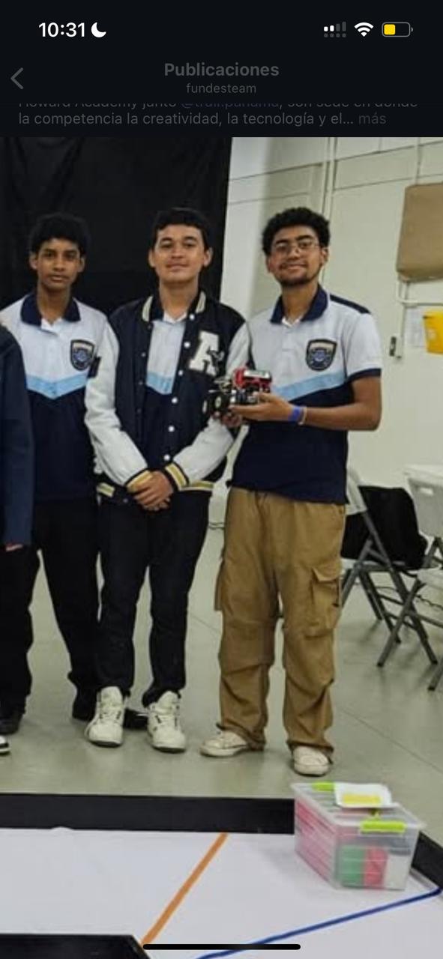
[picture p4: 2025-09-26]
robot photos/2.14/98a59550-f938-4abc-a18e-2ab04d6f916a.jpg

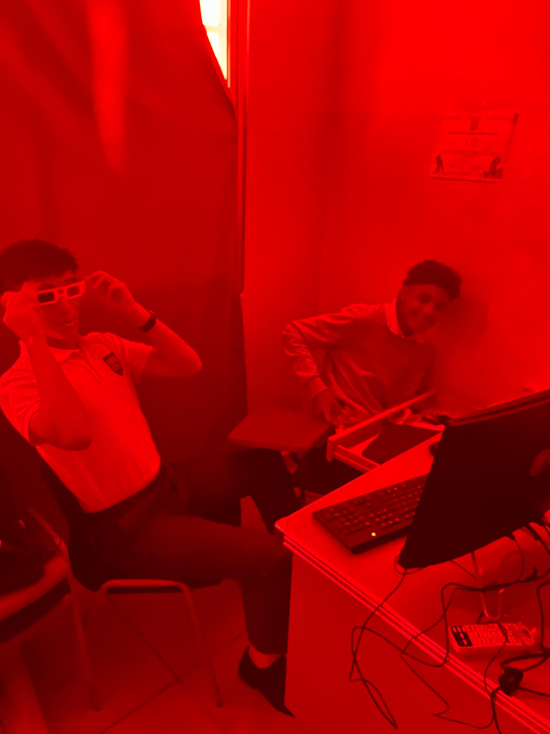
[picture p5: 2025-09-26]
team photos/Funny photos/27a321d2-cd12-4ae4-b40c-0f608639d6a6.jpg

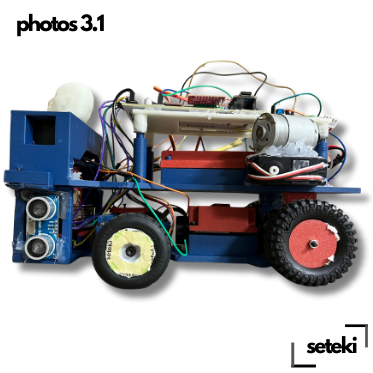
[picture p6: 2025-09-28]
robot photos/3.1 (National)/3.1 Photos (6).png

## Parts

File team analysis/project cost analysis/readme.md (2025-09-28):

# ARA 3.1 Whole project Cost analysis

Orange White Illustration Lifecycle Cost Analysis A4 Document

# End Page
Seteki 2025 - team analysis - project cost analysis

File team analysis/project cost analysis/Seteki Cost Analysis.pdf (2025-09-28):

Product | Description and quantity | Amount ($)
3D Printer | Bambu Lab A1 (1) | 349.00 $
Printer Filament | PETG-CF / SHINY PLA (3) | 68.99 $
Arduino NANO ESP32 | Microcontroller (1) | 19.90 $
PCB Manufactoring | JLC PCB (5 ) - Shipping | 68.90 $
Open MV H7 Plus | Camera (1) | 95.00 $
HC-SRO4 | Ultrasonic Sensors (3) | 15.99 $
Motor 800 RPM | Pololu Motor (1) | 79.00 $
Servo | Injora (1) | 24.99 $
TB6612FNG | Motor Driver (1) | 14.77 $
BNO086 | Gyroscope & the shipping (1) | 73.55 $
Flashlight | For second Challenge (1) | 15.99 $
General Electronic Components | Variety, wires capacitors, diodes, prototype plate | 18.99 $
Total Amount | | 845.07 $

# Seteki Cost Analysis

This seteki 3.1 cost analysis to have a better recovery of all the engineering process

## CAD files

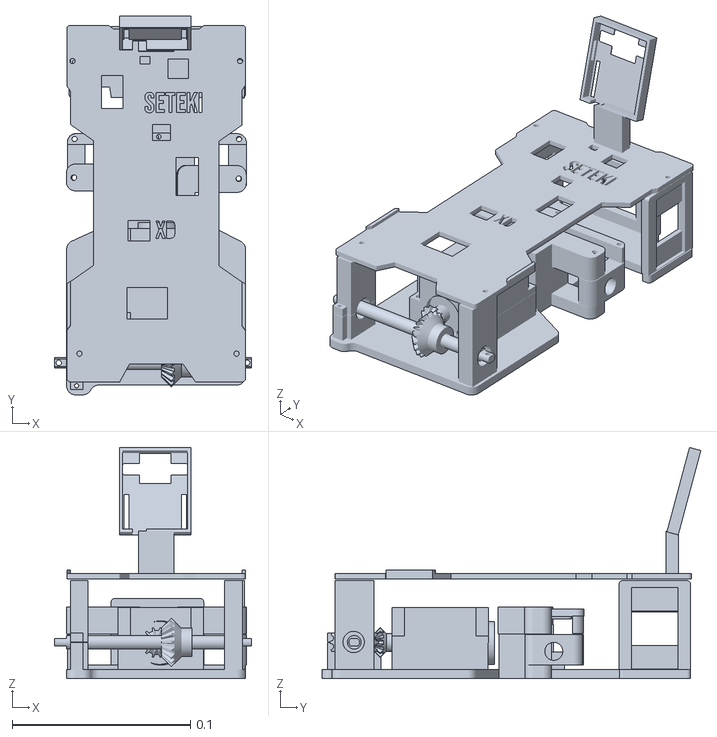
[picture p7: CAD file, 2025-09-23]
ARA Versions/1.1/ARAROBOT 1.1 FULL ASSEMBLY.stl
0.111 x 0.212 x 0.13

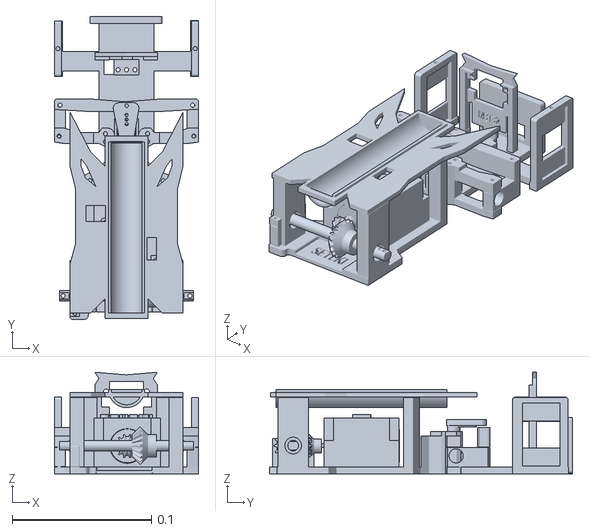
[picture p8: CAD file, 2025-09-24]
ARA Versions/2.14/ARAROBOT 2.14 FULL ASSEMBLY.stl
0.104 x 0.218 x 0.0729

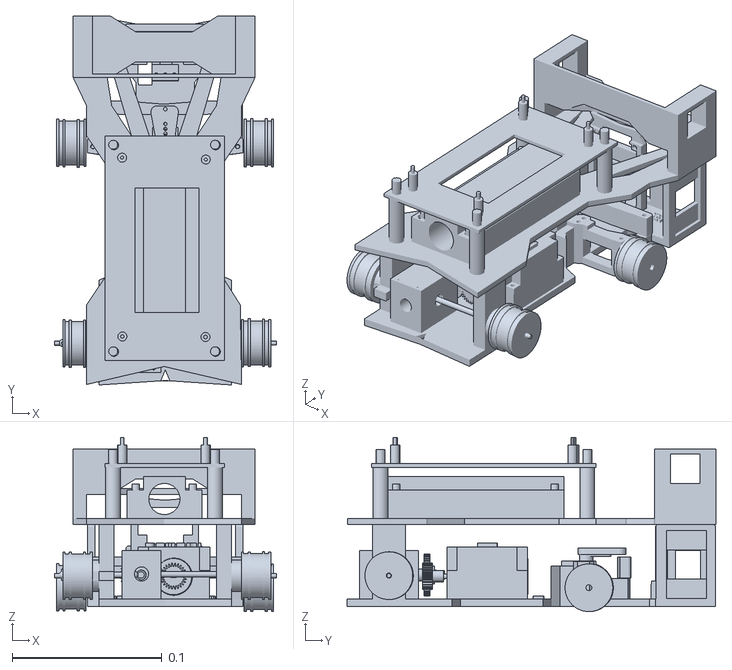
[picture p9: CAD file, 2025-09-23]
3D Models/3.1 (National)/ARAROBOT FULL ASSEMBLY 3.1.stl
0.148 x 0.247 x 0.116

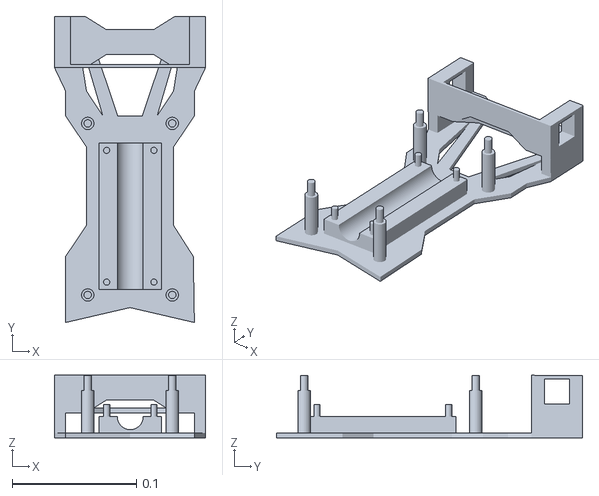
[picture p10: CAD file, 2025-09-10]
3D Models/3.1 (National)/ARAROBOT - Main tape 3.1.stl
0.122 x 0.246 x 0.0503

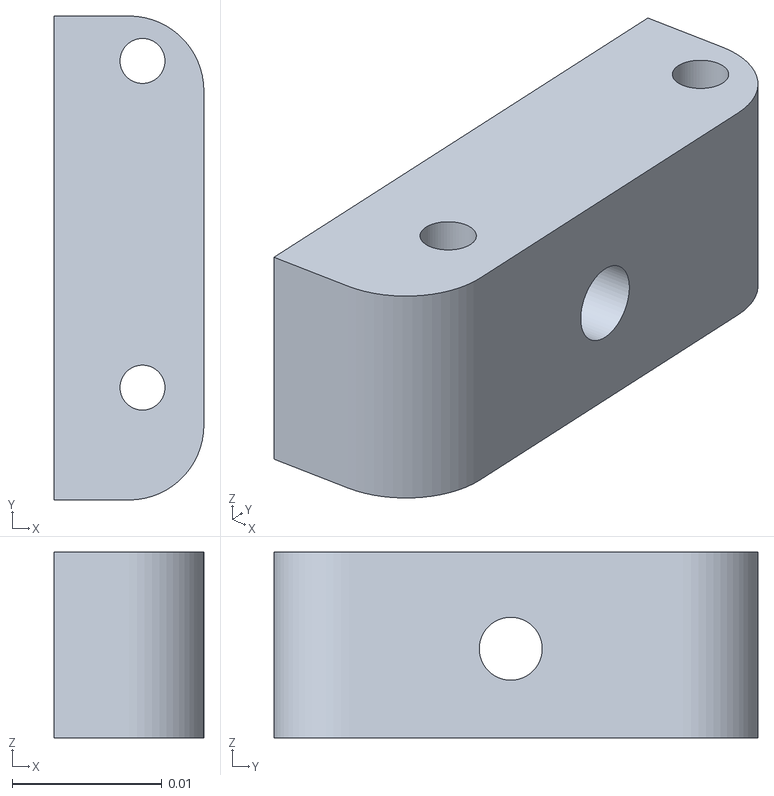
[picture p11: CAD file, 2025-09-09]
3D Models/1.1/ARAROBOT - right catch steering 1.1.stl
0.01 x 0.0323 x 0.0124

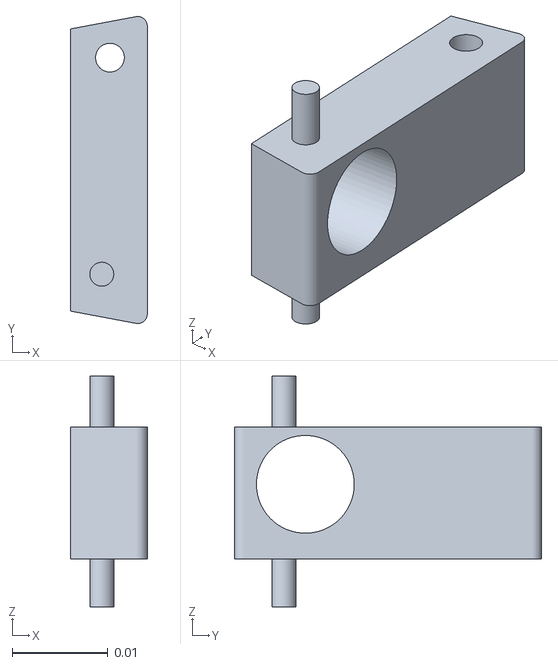
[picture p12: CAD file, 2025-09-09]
3D Models/2.14/ARAROBOT - left steering.stl
0.008 x 0.032 x 0.0241

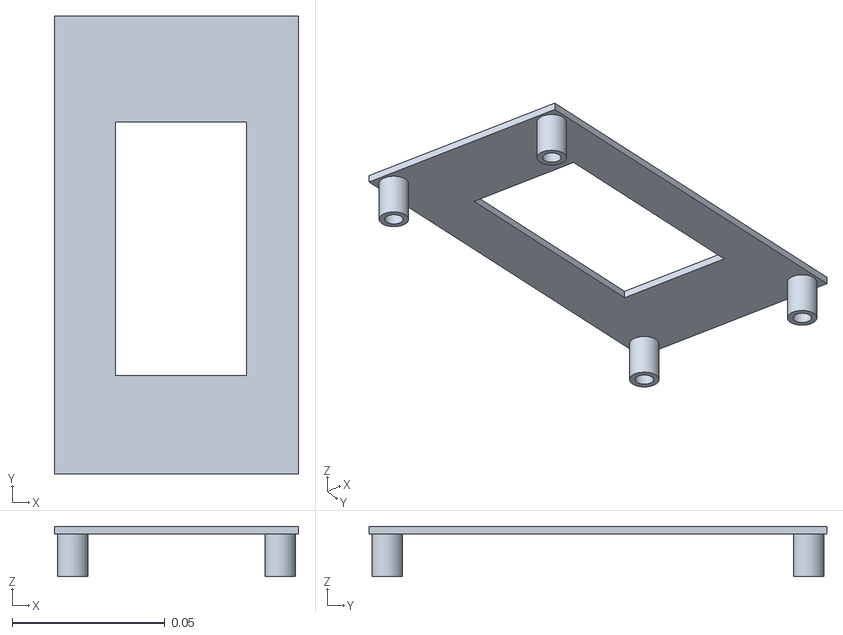
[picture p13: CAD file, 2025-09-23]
3D Models/3.1 (National)/ARAROBOT - PCB Mount tape.stl
0.08 x 0.15 x 0.0165

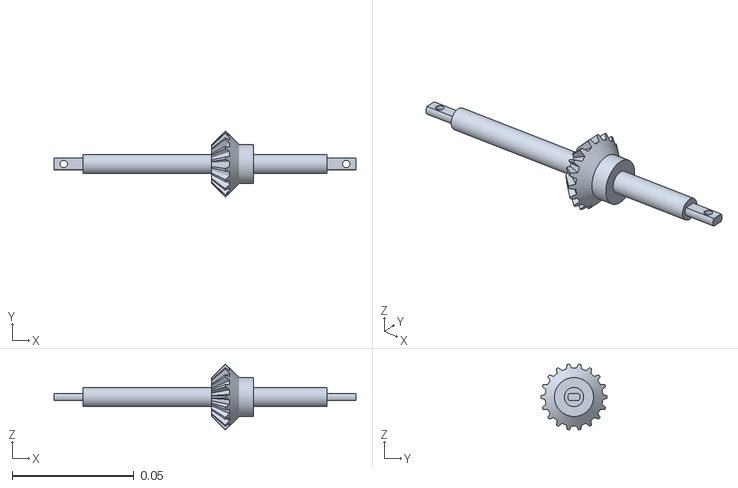
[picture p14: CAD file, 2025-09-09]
3D Models/1.1/ARAROBOT - shaft 1.1.stl
0.124 x 0.0273 x 0.0271

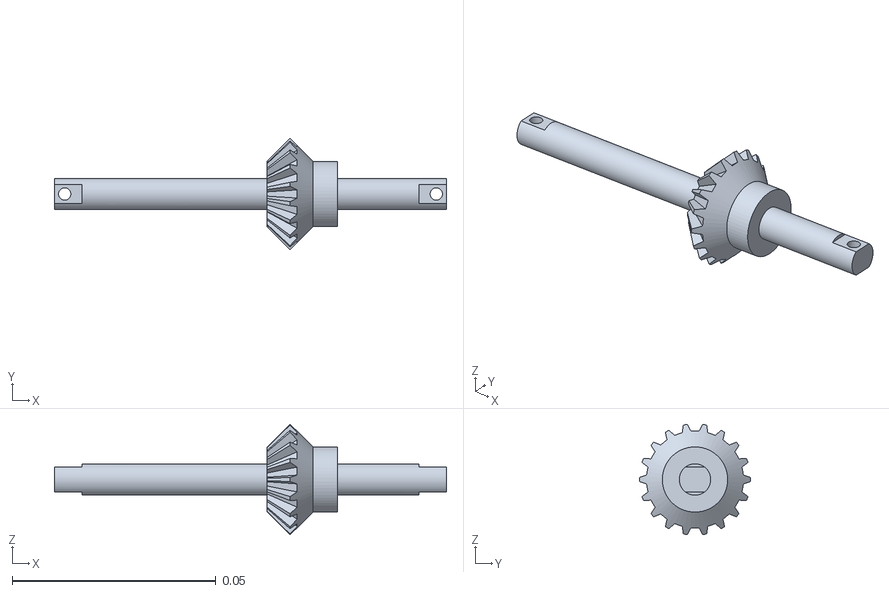
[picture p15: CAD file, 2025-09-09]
3D Models/2.14/ARAROBOT - shaft 2.14.stl
0.0961 x 0.0273 x 0.0271

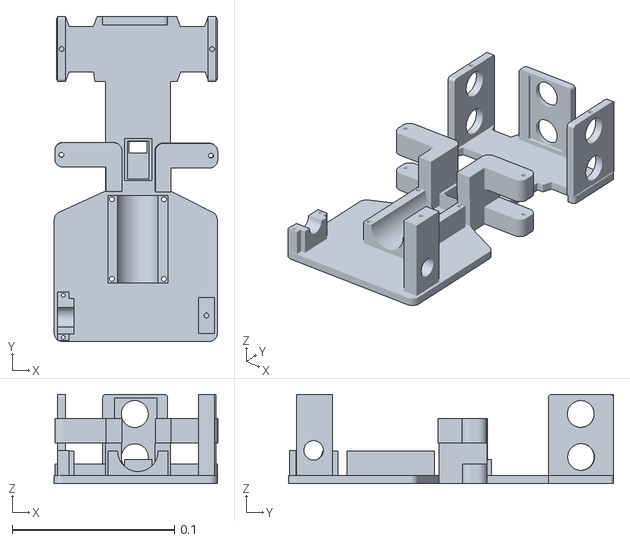
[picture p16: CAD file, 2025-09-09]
3D Models/1.1/ARAROBOT - BODY 1.1.stl
0.101 x 0.2 x 0.055

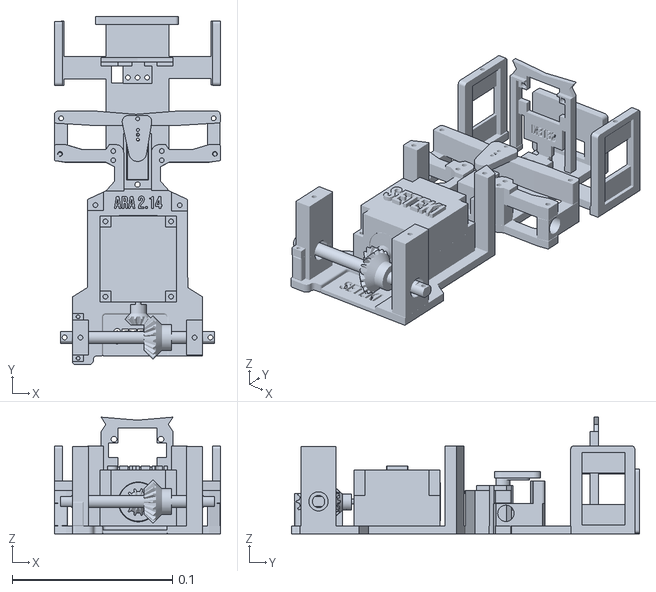
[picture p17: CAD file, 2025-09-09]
3D Models/2.14/ARAROBOT.stl
0.104 x 0.218 x 0.0729

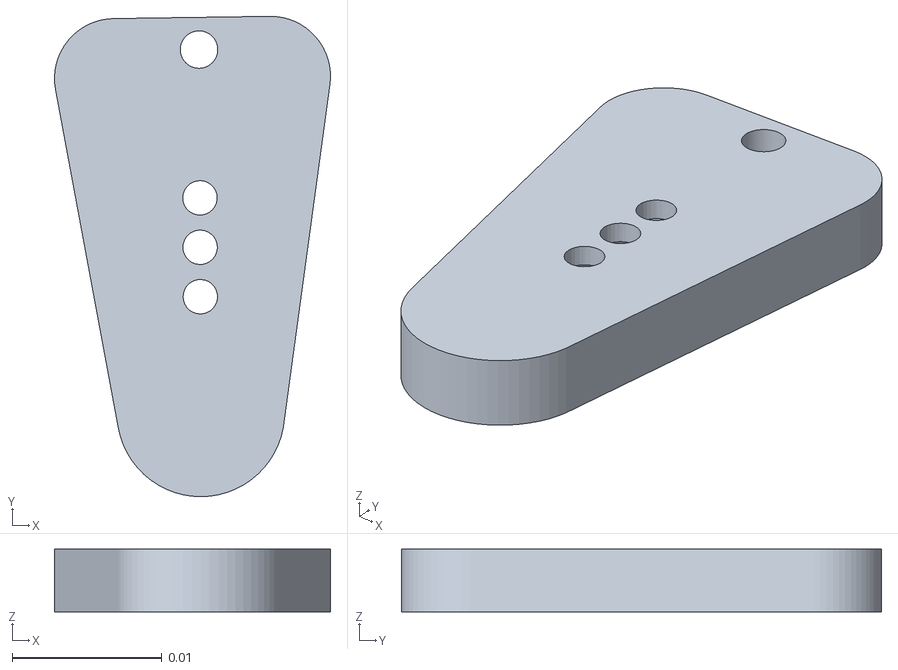
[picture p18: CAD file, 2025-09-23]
3D Models/3.1 (National)/ARAROBOT - 3.1 servo catch.stl
0.0184 x 0.0321 x 0.0042

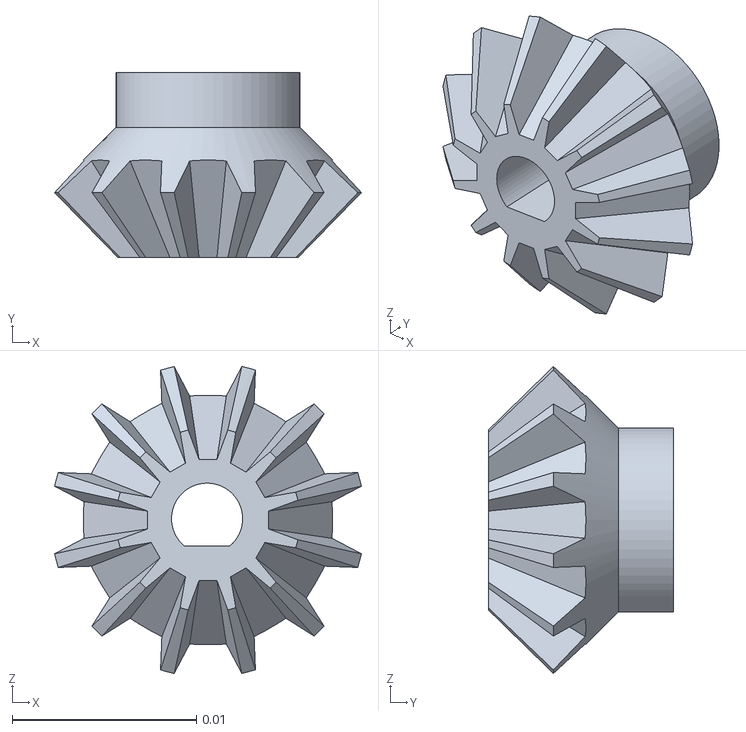
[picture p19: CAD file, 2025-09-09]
3D Models/1.1/ARAROBOT - MOTOR ENTRACE.stl
0.0167 x 0.0101 x 0.0167

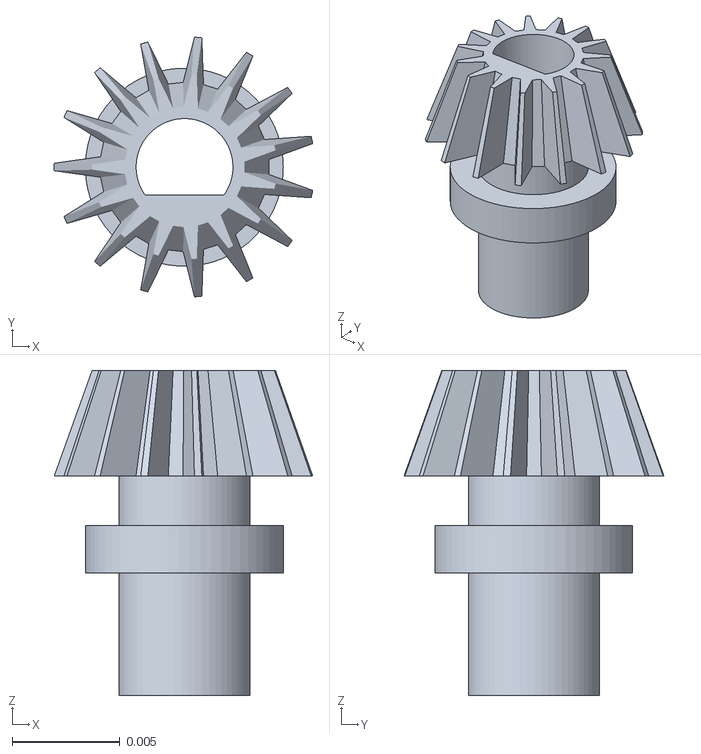
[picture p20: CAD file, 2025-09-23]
3D Models/3.1 (National)/piñon conico diferencial - Part 1 (2).stl
0.012 x 0.0121 x 0.0151

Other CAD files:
3D Models/2.14/ARAROBOT - right steering.stl
3D Models/1.1/ARArobot - LEFT CATCH STEERING.stl
3D Models/2.14/ARAROBOT - upper right steering catch.stl
3D Models/3.1 (National)/ARAROBOT 3.1 steering front bar.stl
3D Models/1.1/ARAROBOT - ARA 1.1.stl
3D Models/1.1/ARAROBOT - Shape line for steering.stl
3D Models/1.1/ARAROBOT - Top plate motor.stl
3D Models/1.1/ARAROBOT - servo catch 1.1.stl
3D Models/1.1/ARAROBOT - top bright motor 1.1.stl
3D Models/2.14/ARAROBOT - Front line steering 2.14.stl
3D Models/2.14/ARAROBOT - SERVO CATCH 2.14.stl
3D Models/2.14/ARAROBOT - body 2.14.stl
3D Models/2.14/ARAROBOT - motor catch 2.14.stl
3D Models/2.14/ARAROBOT - motor mount tape.stl
3D Models/2.14/ARAROBOT - traction balizq.stl
3D Models/2.14/ARAROBOT - upper left steering catch.stl
3D Models/3.1 (National)/ARAROBOT 3.1 national body.stl
3D Models/3.1 (National)/ARAROBOT - 3.1 Motor mount tape.stl
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

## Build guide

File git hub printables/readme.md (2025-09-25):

# PDF Printables
Copy of Add a subheading (16 x 5 cm) (4096 x 2160 px) (7)

Here you can find the PDFs and links to view all the documentation that has been submitted this year.

# End Page
Seteki - GitHub Printables

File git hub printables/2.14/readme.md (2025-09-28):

# Git Hub PDF 2.14
Copy of Add a subheading (16 x 5 cm) (4096 x 2160 px) (10)

# End Page 
Seteki 2025

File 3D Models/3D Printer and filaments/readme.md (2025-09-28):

# Printer
## ` Bambu Lab A1 `

Add a subheading (16 x 5 cm) (4096 x 2160 px) (A4 (Landscape)) (6)

[BUY HERE](https://us.store.bambulab.com/products/a1?srsltid=AfmBOooFc4jPYR_Ln3OijWHlRxdY3ak5R9DcQy4vTf0f34I0BtkTcJZd)

## Filaments

### `Bambu Lab PETG - CF RED` 

Add a subheading (16 x 5 cm) (4096 x 2160 px) (A4 (Landscape)) (8)

[BUY HERE](https://us.store.bambulab.com/products/petg-cf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)

### `Bambu Lab PETG - CF BLUE` 

Add a subheading (16 x 5 cm) (4096 x 2160 px) (A4 (Landscape)) (7)

[BUY HERE](https://us.store.bambulab.com/products/petg-cf)

### `Anycubic PLA Shiny` 

Add a subheading (16 x 5 cm) (4096 x 2160 px) (A4 (Landscape)) (11)

[BUY HERE](https://www.amazon.com/ANYCUBIC-Filament-Dimensional-Accuracy-Printers/dp/B0DH29NHH8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)

## Printer Software
For this project we decide to use the software of the own printer company. BambuStudio
Add a subheading (16 x 5 cm) (4096 x 2160 px) (A4 (Landscape)) (12)

### Download [HERE](https://bambulab.com/en/download/studio)

## Base Plate
We use the bambu original TEXTURIZED PLATE.
Add a subheading (16 x 5 cm) (4096 x 2160 px) (A4 (Landscape)) (13)

## 3D  Timelapse

Here you can see some timelaps of the chassis, and other [ARA 3.1](https://github.com/creditwithout/-/tree/main/ARA%20Versions/3.1%20(National)) Parts.

### `Chassis Timelap`

https://github.com/user-attachments/assets/91b9c366-47d9-474a-a8fe-95e8d2b8927c

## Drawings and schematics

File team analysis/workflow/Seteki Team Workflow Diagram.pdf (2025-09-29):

# seteki workflow

## beyond the future!

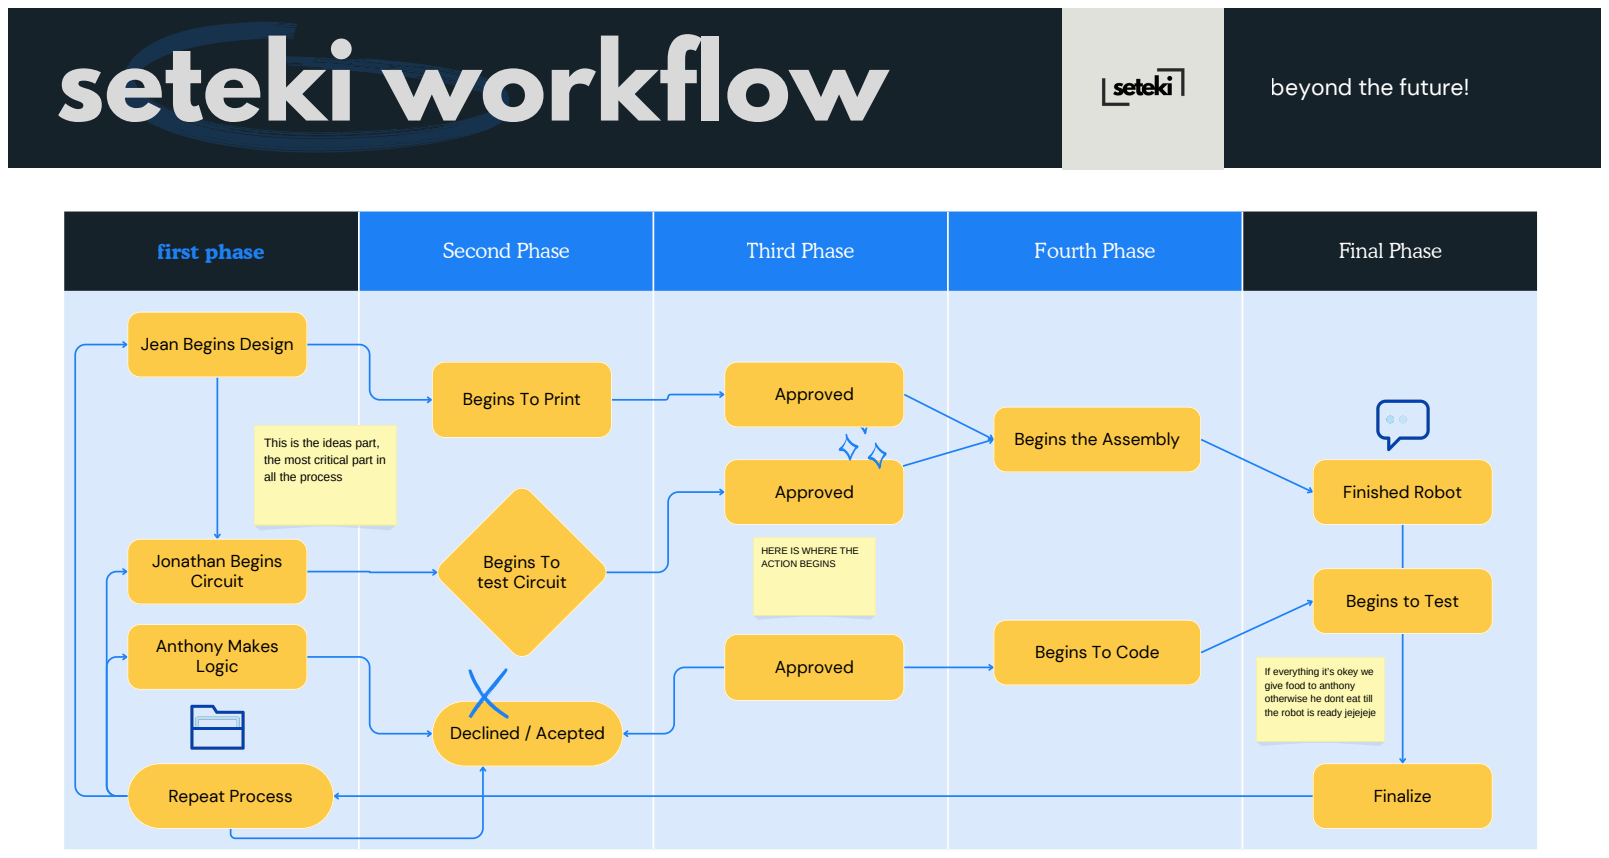
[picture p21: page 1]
first phase; Second Phase; Third Phase; Fourth Phase; Final Phase; Jonathan Begins Circuit; Begins To test Circuit; Declined / Acepted; Finished Robot; Repeat Process; Finalize; Approved; Anthony Makes Logic

Jean Begins Design

Begins To Print

Begins the Assembly

This is the ideas part,
the most critical part in
all the process

HERE IS WHERE THE
ACTION BEGINS

Begins to Test

Begins To Code

If everything it’s okey we
give food to anthony
otherwise he dont eat till
the robot is ready jejejeje

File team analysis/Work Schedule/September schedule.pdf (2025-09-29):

# AVERAGE WEEK SEPTEMBER

# seteki

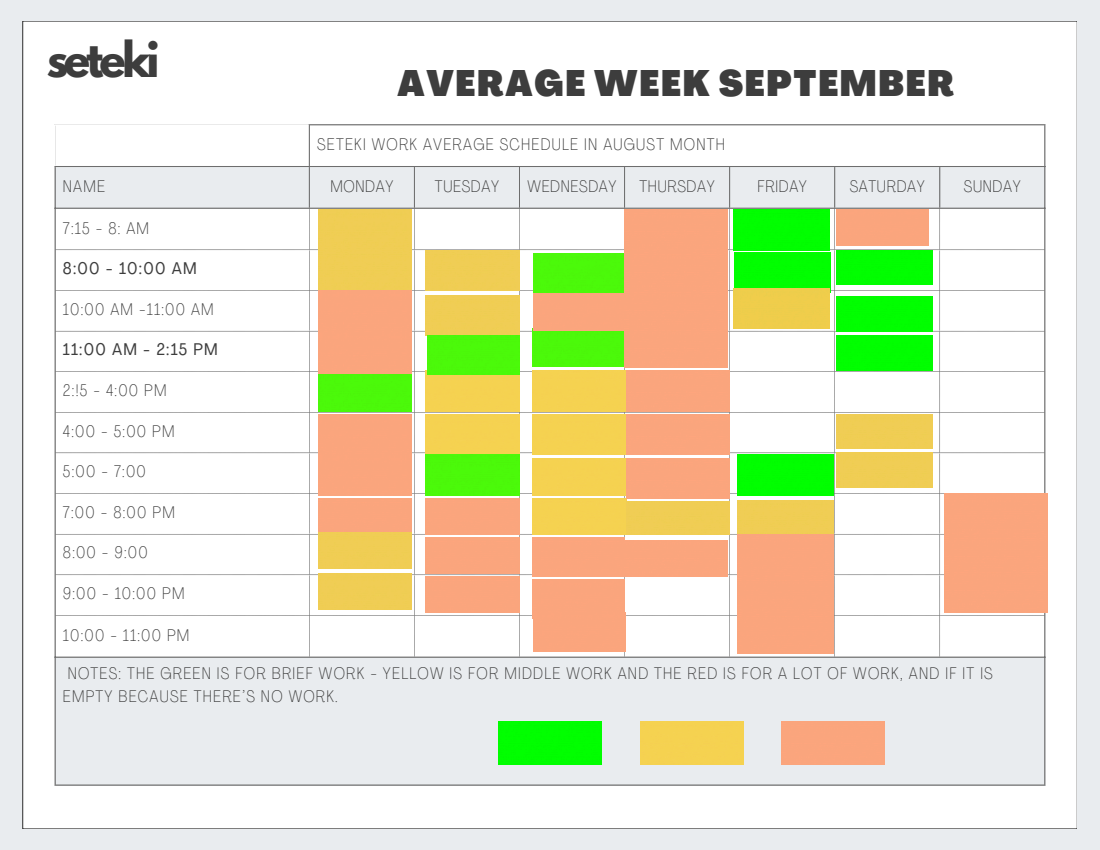
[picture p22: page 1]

SETEKI WORK AVERAGE SCHEDULE IN AUGUST MONTH

NAME | MONDAY | TUESDAY | WEDNESDAY | THURSDAY | FRIDAY | SATURDAY | SUNDAY

NOTES: THE GREEN IS FOR BRIEF WORK - YELLOW IS FOR MIDDLE WORK AND THE RED IS FOR A LOT OF WORK, AND IF IT IS
EMPTY BECAUSE THERE’S NO WORK.

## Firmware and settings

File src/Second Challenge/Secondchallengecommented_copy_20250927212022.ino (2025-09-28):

#include "SparkFun_BNO080_Arduino_Library.h"
#include <Wire.h>
#include <ESP32Servo.h>
#include <stdlib.h>
#include <math.h>
#include <string.h>
#if __has_include(<NewPing.h>)
#include <NewPing.h>
#define USE_NEWPING 1
#else
#define USE_NEWPING 0
#endif
// ==================== CONFIGURABLE PARAMETERS SECTION ====================
// Hardware pin assignments for all robot components
const int servoPin = 8;        // Servo motor control pin for steering
const int pwma = 9;            // PWM pin for motor speed control (H-bridge)
const int ain2 = 10;           // Motor direction control pin A2 (H-bridge L298N)
const int ain1 = 11;           // Motor direction control pin A1 (H-bridge L298N)
const int stby = 12;           // Standby/enable pin for motor driver H-bridge
const int startButtonPin = A0; // Start button input pin with internal pullup
#define TRIG_IZQUIERDO 5    // Left ultrasonic sensor trigger pin
#define ECHO_IZQUIERDO 4     // Left ultrasonic sensor echo pin
#define TRIG_DERECHA 7       // Right ultrasonic sensor trigger pin
#define ECHO_DERECHA 6       // Right ultrasonic sensor echo pin
#define TRIG_CENTRO A2       // Center ultrasonic sensor trigger pin
#define ECHO_CENTRO A1       // Center ultrasonic sensor echo pin
#define CAM_RX_PIN A7        // Camera UART receive pin for serial communication
#define CAM_TX_PIN A6        // Camera UART transmit pin for serial communication

// IMU sensor configuration and I2C bus setup
const uint8_t I2C_SDA_PIN = A4;              // I2C data line pin for sensor communication
const uint8_t I2C_SCL_PIN = A5;              // I2C clock line pin for sensor communication
const uint8_t BNO08X_INT_PIN = 2;            // BNO080 IMU interrupt pin for data ready signal
const uint8_t BNO08X_RST_PIN = 3;            // BNO080 IMU reset pin for hardware reset capability
const uint8_t BNO08X_ADDR = 0x4B;            // I2C address of BNO080 IMU sensor
const uint16_t IMU_ROTATION_VECTOR_PERIOD_MS = 50;  // IMU data update rate in milliseconds (20Hz)

// Servo motor configuration and angle limits
const int servoNeutral = 90;   // Neutral position for straight ahead steering (90 degrees)
const int servoMinAngle = 60;  // Minimum servo angle limit for left steering (30 degrees from neutral)
const int servoMaxAngle = 120; // Maximum servo angle limit for right steering (30 degrees from neutral)

// PID controller gains for different navigation phases
float Kp = 1.5, Ki = 0.05, Kd = 0.8;           // Normal navigation PID gains (proportional, integral, derivative)
float Kp_turn = 2.0, Ki_turn = 0.02, Kd_turn = 0.7;  // Turning maneuver PID gains for sharper response
float Kp_stab = 1.2, Ki_stab = 0.03, Kd_stab = 1.0;  // Stabilization PID gains for smooth corrections
const unsigned long sampleInterval = 20;       // PID calculation interval in microseconds (50Hz)
const float integralLimit = 40.0;              // Integral windup protection limit to prevent overshoot
const float deadband = 0.5;                    // Deadband for forward motion to prevent oscillation
const float deadband_reversa = 1.5;            // Larger deadband for reverse motion due to different dynamics

// Motor speed ramping parameters for smooth acceleration and deceleration
const unsigned long MOTOR_RAMP_INTERVAL_MS = 20;  // Motor ramp update interval in milliseconds (50Hz)
const int MOTOR_ACCEL = 15;                       // Acceleration rate per update cycle (PWM units)
const int MOTOR_DECEL = 25;                       // Deceleration rate per update cycle (PWM units)

// Navigation and curve detection parameters
const int NUM_CURVAS_ANTES_DE_PARAR = 12;         // Maximum number of turns before parking sequence
const float UMBRAL_APERTURA_LATERAL = 80.0;       // Lateral opening threshold for turn detection
const float UMBRAL_DISTANCIA_FRONTAL_GIRO = 85.0; // Front distance threshold to initiate turn
const float DISTANCIA_SECCION_CURVA_CM = 110.0;   // Distance that defines the curve section after turn
const float UMBRAL_FRONTAL_PARA_INICIAR_GIRO_CM = 15.0;  // Front distance to start turning
const float DISTANCIA_REVERSA_C1_CM = 15.0;       // Reverse distance after turn in Lane 1
const float DISTANCIA_REVERSA_C2_CM = 20.0;       // Reverse distance after turn in Lane 2

// Lane detection thresholds based on lateral distance measurements
const float CARRIL_UMBRAL_1 = 40.0;  // Distance threshold to identify Lane 1 (closest to wall)
const float CARRIL_UMBRAL_2 = 55.0;  // Distance threshold to identify Lane 2 (middle lane)

// Ultrasonic sensor configuration and filtering parameters
const long TIMEOUT_ULTRASONICO = 20000;          // Ultrasonic measurement timeout in microseconds
const float DISTANCIA_MAX_VALIDA = 500.0;        // Maximum valid distance reading in centimeters
const float DISTANCIA_MIN_VALIDA = 1.0;          // Minimum valid distance reading in centimeters
#if USE_NEWPING
const unsigned int MAX_US_DISTANCE_CM = 200;     // Maximum measurable distance for NewPing library
#endif
const unsigned long MIN_INTERVALO_PING_MS = 15; // Minimum interval between ultrasonic pings in milliseconds

// Speed settings and timing parameters for different navigation phases
const int velocidadNormal = 180;                  // Normal forward navigation speed (PWM value)
const int velocidadGiro = 180;                   // Turning maneuver speed (PWM value)
const int VELOCIDAD_SALIDA_PARKING = 180;        // Speed for parking exit maneuvers (PWM value)
const unsigned long TIEMPO_REVERSA_INICIAL_MS = 800;   // Initial reverse time during parking exit
const unsigned long TIEMPO_AVANCE_SALIDA_MS = 1800;    // Forward movement time during parking exit
const float YAW_ALIGNED_TOLERANCE = 2.0;        // Yaw alignment tolerance for precise positioning
const float YAW_TOLERANCE_SECCION_CURVA = 15.0; // Yaw tolerance in curve section during obstacle avoidance
const float YAW_TOLERANCE_GIRO = 5.0;           // Yaw tolerance for completing 90-degree turns
const int VELOCIDAD_ALINEACION_YAW = 140;       // Speed for yaw alignment maneuvers (PWM value)
const unsigned long TIEMPO_REVERSA_FINAL_MS = 3000;    // Final reverse time during parking exit
const unsigned long TIMEOUT_YAW_ALIGN_MS = 2554;       // Timeout for yaw alignment operations

// Camera vision system and blob detection parameters
const int BLOB_CONFIRMATION_CYCLES = 10;       // Number of consecutive frames required to confirm blob detection
const float UMBRAL_DETENCION_FRONTAL = 10.0;   // Single threshold for stopping due to front proximity
const size_t CAM_BUFFER_SIZE = 64;             // Size of camera UART communication buffer

// Obstacle avoidance maneuver parameters
const float ANGULO_ESQUIVE = 40.0;            // Initial turn angle in degrees for standard avoidance
const float ANGULO_ESQUIVE_FUERTE = 45.0;     // Stronger turn angle in degrees for pronounced avoidance
const float TOLERANCIA_ANGULO_ESQUIVE = 3.0;  // Angular tolerance for completing avoidance turns
const float UMBRAL_PASILLO_LIBRE_CM = 35.0;   // Front distance threshold indicating clear passage
const int VEL_ESQUIVE_MIN = 120;              // Minimum speed during obstacle avoidance (PWM value)
const int VEL_ESQUIVE_MAX = 180;              // Maximum speed during obstacle avoidance (PWM value)

// Rotary encoder configuration for distance measurement
#define ENCODER_PIN_A 13        // Encoder channel A pin for quadrature detection
#define ENCODER_PIN_B A3        // Encoder channel B pin for quadrature detection (GPIO 39 on most ESP32)
const float PULSOS_POR_CM = 54.6;  // Calibrated pulses per centimeter for distance calculation

// Safety system parameters for collision avoidance and emergency maneuvers
const float UMBRAL_LATERAL_SAFETY_CM = 18.0f;              // Lateral safety threshold for emergency corrections
const float YAW_SAFETY_BIAS_MAX = 12.0f;                   // Maximum yaw safety bias in degrees
const float YAW_SAFETY_BIAS_K = 0.6f;                      // Yaw bias gain per cm below threshold (deltaL - deltaR)
const float UMBRAL_FRONTAL_ABORT_ESQUIVE_CM = 15.0f;       // Front distance threshold to abort avoidance maneuver
const float UMBRAL_FRONTAL_SEGURIDAD_SECCION_CM = 20.0f;   // Front safety threshold in curve section
const float DISTANCIA_RETROCESO_SEGURIDAD_SECCION_CM = 15.0f;  // Safety reverse distance in curve section
const float LATERAL_OBJETIVO_PEGADO_CM = 75.0f;            // Target lateral distance for wall-following behavior
const float PEGADO_BIAS_DEG = 8.0f;                        // Steering bias in degrees for wall-following
// ================= END OF CONFIGURABLE PARAMETERS =================
// ==================== GLOBAL PARAMETERS SECTION ====================
// Core sensor and control objects
BNO080 myIMU;                    // IMU sensor object for orientation and yaw data
Servo steeringServo;             // Servo motor object for steering control

// Yaw control and calibration variables
float yawOffset = 0.0f;          // Yaw offset for relative orientation measurement
bool offsetSet = false;          // Flag indicating if yaw offset has been calibrated
float setpoint = 0.0;            // Current yaw setpoint for PID control
float targetSetpoint = 0.0;      // Target yaw setpoint for maneuver planning

// PID controller state variables
float error = 0.0, prevError = 0.0;           // Current and previous yaw errors
float integral = 0.0, derivative = 0.0, pidOutput = 0.0;  // PID controller terms
unsigned long prevTimePID = 0;                // Previous PID calculation timestamp
float setpoint_actual_debug = 0.0;           // Debug variable for setpoint tracking
float dt_global = 0.02f;                     // Global delta time for PID calculations
float currentYaw = 0.0f;                     // Current relative yaw angle in degrees
// Main robot state machine enumeration
enum EstadoRobot { SALIR_PARKING, NORMAL, EN_MANIOBRA, CORRECCION_REVERSA, ESPERANDO_RESPUESTA_CAMARA, MANIOBRA_CARRIL_3, ESQUIVAR_BLOQUE, ESPERANDO_CONFIRMACION_PARED, DETENIDO };
EstadoRobot estadoActual = NORMAL;  // Current robot state
bool iniciandoReversa = false;      // Flag to manage safe transition to reverse motion

// Direction enumeration for turn management
enum DireccionGiro { NINGUNA, IZQUIERDA, DERECHA };  // Turn direction states

// Obstacle avoidance sub-state machine
enum SubEstadoEsquivar { ES_NINGUNO, ES_GIRO_INICIAL, ES_AVANCE_PARALELO, ES_GIRO_REGRESO };
SubEstadoEsquivar subEstadoEsquivar = ES_NINGUNO;  // Current avoidance sub-state
const char* subEstadoEsquivarNombres[] = {"NINGUNO", "GIRO_INI", "AVANCE_PAR", "GIRO_REG"};  // Sub-state names for debugging
// Maneuver execution sub-state machine for turn coordination
enum SubEstadoManiobra { M_INICIO, M_AVANCE_RECTO, M_GIRO_EN_CURVA };  // Maneuver sub-states
SubEstadoManiobra subEstadoManiobra = M_INICIO;  // Current maneuver sub-state
const char* subEstadoManiobraNombres[] = {"M_INICIO", "M_AVANCE", "M_GIRO"};  // Sub-state names for debugging
unsigned long tiempoInicioSubEstadoManiobra = 0;  // Maneuver sub-state start timestamp
float distanciaReversaObjetivo = 0.0f;           // Target reverse distance for CORRECCION_REVERSA state

// Obstacle avoidance maneuver variables
float yawInicialManiobra = 0.0f;    // Initial yaw angle when avoidance maneuver starts
float setpointEsquive = 0.0f;       // Target yaw setpoint during avoidance maneuver
DireccionGiro direccionEsquive = NINGUNA;  // Direction of current avoidance maneuver
float anguloEsquiveActual = 0.0f;   // Current avoidance turn angle in degrees

// State machine debugging and identification
const char* estadoNombres[] = {"SALIR_PARKING", "NORMAL", "EN_MANIOBRA", "CORRECCION_REVERSA", "ESPERANDO_RESP_CAM", "MANIOBRA_C3", "ESQUIVAR_BLOQUE", "ESP_CONF_PARED", "DETENIDO"};  // State names for debugging
// Parking exit sub-state machine for coordinated exit maneuvers
enum SubEstadoSalirParking { SP_INICIO, SP_REVERSA_GIRANDO, SP_AVANCE_SALIDA, SP_CORRIGIENDO_YAW, SP_REVERSA_FINAL, SP_ESPERANDO_CAMARA };
SubEstadoSalirParking subEstadoParking = SP_INICIO;  // Current parking exit sub-state
const char* subEstadoParkingNombres[] = {"INICIO", "REVERSA_INI", "AVANCE_SAL", "CORRIGE_YAW", "REVERSA_FIN", "ESP_CAM"};  // Sub-state names for debugging

// Lane identification and Lane 3 special maneuver handling
int carrilActual = 0;  // Current lane identification (0=unknown, 1=inner, 2=middle, 3=outer)
enum SubEstadoManiobraC3 { MC3_INICIO, MC3_AVANCE_RECTO, MC3_REVERSA_GIRANDO };  // Lane 3 maneuver sub-states
SubEstadoManiobraC3 subEstadoC3 = MC3_INICIO;  // Current Lane 3 maneuver sub-state
const char* subEstadoC3Nombres[] = {"INICIO_C3", "AVANCE_C3", "REVERSA_C3"};  // Sub-state names for debugging
// Navigation state tracking variables
unsigned int contadorCurvas = 0;           // Counter for completed turns in the circuit
DireccionGiro direccionPrimerGiro = NINGUNA;  // Direction of first turn (for consistency throughout circuit)

// Timing and state transition management
unsigned long tiempoInicioSubEstadoParking = 0;  // Parking sub-state start timestamp
unsigned long tiempoInicioSubEstadoC3 = 0;       // Lane 3 maneuver sub-state start timestamp
unsigned long tiempoUltimaManiobra = 0;          // Last maneuver completion timestamp
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
void loop() {
    if (estadoActual == DETENIDO) {
        detenerMotor();
        actualizarMotorConRampa();
        digitalWrite(stby, LOW);
        return;
    }
    actualizarMotorConRampa();
    actualizarSeccionDeCurva();
    if (myIMU.hasReset()) {
      manejarReinicioIMU();
      return;
    }
    if (myIMU.dataAvailable()) {
        ultimoTiempoDatosImu = millis();
        float qI = myIMU.getQuatI();
        float qJ = myIMU.getQuatJ();
        float qK = myIMU.getQuatK();
        float qReal = myIMU.getQuatReal();
        float siny_cosp = 2.0 * (qReal * qK + qI * qJ);
        float cosy_cosp = 1.0 - 2.0 * (qJ * qJ + qK * qK);
        float yaw = atan2(siny_cosp, cosy_cosp);
        float currentYawDegrees = yaw * 180.0 / M_PI;
        if (!offsetSet) { yawOffset = currentYawDegrees; offsetSet = true; }
        float relativeYaw = currentYawDegrees - yawOffset;
        if (relativeYaw > 180.0f) relativeYaw -= 360.0f;
        else if (relativeYaw < -180.0f) relativeYaw += 360.0f;
        currentYaw = -relativeYaw;
    }
    procesarSerialCamara();
#if USE_NEWPING
    servicioUltrasonidos();
#endif
    actualizarFiltrosSensores();

    if (estadoActual != ESQUIVAR_BLOQUE && estadoActual != DETENIDO) {
        if (seccionBlob != 0) {
            blobDetectionCounter++;
        } else {
            blobDetectionCounter = 0;
        }

        if (blobDetectionCounter >= BLOB_CONFIRMATION_CYCLES) {
            if(estadoActual == EN_MANIOBRA) {
                integral = 0.0f; derivative = 0.0f;
            }
            // --- NUEVO: Gating por color y por sección ---
            bool esRojo = (seccionBlob >= 1 && seccionBlob <= 6);
            ColorBloque colorDetectado = esRojo ? COLOR_ROJO : COLOR_VERDE;
            bool permitirEsquive = true;
            if (bloquearEsquiveEnSeccion && enSeccionDeCurva) {
                permitirEsquive = false;
            }
            if (permitirEsquive && ultimoColorEsquivado != COLOR_NINGUNO && ultimoColorEsquivado == colorDetectado) {
                permitirEsquive = false;
            }
            if (permitirEsquive) {
                Serial.print("ESQUIVAR: Bloque confirmado. S: "); Serial.println(seccionBlob);
                estadoActual = ESQUIVAR_BLOQUE;
            } else {
                Serial.println("ESQUIVAR: Bloque ignorado por regla de color o seccion.");
            }
            blobDetectionCounter = 0; // Resetear para la proxima
        }
    }

    actualizarControl();
    manejarEstados();
    static unsigned long lastPrintTime = 0;
    if (millis() - lastPrintTime > 300) {
        Serial.print("estado:"); Serial.print(estadoNombres[estadoActual]);
        if (estadoActual == SALIR_PARKING) {
            Serial.print("/"); Serial.print(subEstadoParkingNombres[subEstadoParking]);
        }
        if (estadoActual == EN_MANIOBRA) {
            Serial.print("/"); Serial.print(subEstadoManiobraNombres[subEstadoManiobra]);
        }
        if (estadoActual == MANIOBRA_CARRIL_3) {
            Serial.print("/"); Serial.print(subEstadoC3Nombres[subEstadoC3]);
        }
        if (estadoActual == ESQUIVAR_BLOQUE) {
            Serial.print("/"); Serial.print(subEstadoEsquivarNombres[subEstadoEsquivar]);
        }
        Serial.print("|Carril:"); Serial.print(carrilActual);
        Serial.print("|Yaw:"); Serial.print(currentYaw, 1);
        Serial.print("|SetP:"); Serial.print(setpoint_actual_debug, 1);
        Serial.print("|ErrY:"); Serial.print(error, 1);
        Serial.print("|DI:"); Serial.print(distanciaIzquierdoFiltrada, 0);
        Serial.print("|DCent:"); Serial.print(distanciaCentroRaw, 0);
        Serial.print("|DD:"); Serial.print(distanciaDerechoFiltrada, 0);
        Serial.print("|Sect:"); Serial.print(seccionBlob);
        Serial.print("|Roi:"); Serial.print(roiBlob);
        Serial.print("|curv:"); Serial.print(contadorCurvas);
        Serial.print("|SC:"); Serial.print(enSeccionDeCurva);
        Serial.print("|Srv:"); Serial.print(steeringServo.read());
        Serial.println();
        lastPrintTime = millis();
    }
}

void actualizarControl() {
    unsigned long currentTime = micros();
    unsigned long elapsedTime = currentTime - prevTimePID;
    if (elapsedTime <= 0) elapsedTime = sampleInterval * 1000UL;
    dt_global = elapsedTime / 1000000.0f;
    prevTimePID = currentTime;
    if (estadoActual == DETENIDO || estadoActual == ESPERANDO_RESPUESTA_CAMARA || estadoActual == ESPERANDO_CONFIRMACION_PARED) {
        integral = 0.0;
        return;
    }

    float kp_actual, ki_actual, kd_actual;
    float setpoint_actual_yaw;
    switch(estadoActual) {
        case SALIR_PARKING:
            kp_actual = Kp; ki_actual = Ki; kd_actual = Kd;
            setpoint_actual_yaw = 0.0f;
            break;
        case EN_MANIOBRA:
            if (subEstadoManiobra == M_AVANCE_RECTO) {
                kp_actual = Kp; ki_actual = Ki; kd_actual = Kd;
                setpoint_actual_yaw = setpoint;
            } else { // M_GIRO_EN_CURVA o M_INICIO
                kp_actual = Kp_turn; ki_actual = Ki_turn; kd_actual = Kd_turn;
                setpoint_actual_yaw = targetSetpoint;
            }
            break;
        case MANIOBRA_CARRIL_3:
            if (subEstadoC3 == MC3_AVANCE_RECTO) {
                kp_actual = Kp; ki_actual = Ki; kd_actual = Kd;
                setpoint_actual_yaw = setpoint;
            } else {
                kp_actual = Kp_turn; ki_actual = Ki_turn; kd_actual = Kd_turn;
                setpoint_actual_yaw = targetSetpoint;
            }
            break;
        case CORRECCION_REVERSA: {
            kp_actual = Kp_stab;
            ki_actual = Ki_stab;
            kd_actual = Kd_stab;
            setpoint_actual_yaw = setpoint;
            break;
        }
        case NORMAL: {
            kp_actual = Kp;
            ki_actual = Ki;
            kd_actual = Kd;
            setpoint_actual_yaw = setpoint;
            break;
        }
        case ESQUIVAR_BLOQUE: {
            // --- NUEVO: Abortos por seguridad lateral y frontal ---
            if (distanciaIzquierdoFiltrada < UMBRAL_LATERAL_SAFETY_CM || distanciaDerechoFiltrada < UMBRAL_LATERAL_SAFETY_CM) {
                Serial.println(">>> ESQUIVAR: Lateral demasiado cerca, abortando y corrigiendo yaw.");
                setpoint = yawInicialManiobra;
                targetSetpoint = setpoint;
                integral = 0.0f; derivative = 0.0f; prevError = 0.0f;
                ultimoColorEsquivado = (seccionBlob >= 1 && seccionBlob <= 6) ? COLOR_ROJO : COLOR_VERDE;
                seccionBlob = 0; roiBlob = -1;
                estadoActual = NORMAL;
                subEstadoEsquivar = ES_NINGUNO;
                break;
            }
            if (distanciaCentroFiltrada < UMBRAL_FRONTAL_ABORT_ESQUIVE_CM) {
                Serial.println(">>> ESQUIVAR: Frontal demasiado cerca, abortando y corrigiendo yaw.");
                setpoint = yawInicialManiobra;
                targetSetpoint = setpoint;
                integral = 0.0f; derivative = 0.0f; prevError = 0.0f;
                ultimoColorEsquivado = (seccionBlob >= 1 && seccionBlob <= 6) ? COLOR_ROJO : COLOR_VERDE;
                seccionBlob = 0; roiBlob = -1;
                estadoActual = NORMAL;
                subEstadoEsquivar = ES_NINGUNO;
                break;
            }
             kp_actual = Kp_turn;
             ki_actual = Ki_turn;
             kd_actual = Kd_turn;
             setpoint_actual_yaw = setpointEsquive;
             break;
        }
        default:
            kp_actual = Kp; ki_actual = Ki; kd_actual = Kd;
            setpoint_actual_yaw = setpoint;
            break;
    }
    setpoint_actual_debug = setpoint_actual_yaw;
    error = calcularErrorAngular(setpoint_actual_yaw, currentYaw);
    bool enReversa = (estadoActual == CORRECCION_REVERSA) ||
                     (estadoActual == SALIR_PARKING && (subEstadoParking == SP_REVERSA_GIRANDO || subEstadoParking == SP_REVERSA_FINAL)) ||
                     (estadoActual == MANIOBRA_CARRIL_3 && subEstadoC3 == MC3_REVERSA_GIRANDO);
    if (enReversa) {
        if (fabs(error) < deadband_reversa) { error = 0.0f; }
    } else {
        if (fabs(error) < deadband) { error = 0.0f; }
    }
    integral += error * dt_global;
    integral = constrain(integral, -integralLimit, integralLimit);
    derivative = (dt_global > 0.0001f) ? (error - prevError) / dt_global : 0.0f;
    prevError = error;
    pidOutput = (kp_actual * error) + (ki_actual * integral) + (kd_actual * derivative);
    
    float comandoTotal = pidOutput;
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

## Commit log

2025-09-09 Add files via upload
    ARA ROBOT 1.1 FILES 3 MODELS... SETEKI
    [ARAROBOT - BODY 1.1.stl, ARAROBOT - MOTOR ENTRACE.stl, ARAROBOT - Shape line for steering.stl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]
2025-09-09 Add files via upload
    3D MODEL ARA ROBT 2.14
    [ARAROBOT - CARRIER open mv.stl, ARAROBOT - Front line steering 2.14.stl, ARAROBOT - SERVO CATCH 2.14.stl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]
2025-09-23 Add files via upload
    3.1 national stl
    [ARAROBOT - 3.1 Motor mount tape.stl, ARAROBOT - 3.1 right steering arm.stl, ARAROBOT - 3.1 sHAFT.stl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]
2025-09-23 Add files via upload
    1.1
    [ARAROBOT 1.1 FULL ASSEMBLY.stl]
2025-09-24 Add files via upload
    2.14 FULL ASSEMBLY
    [ARAROBOT 2.14 FULL ASSEMBLY.stl]
